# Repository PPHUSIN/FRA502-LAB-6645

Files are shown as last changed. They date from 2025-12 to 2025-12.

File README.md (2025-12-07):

# THRUST VECTORING DRONE
**FIBO FRA502 – RoboticsDev Final Project 2025**

**Institute of Field Robotics, King Mongkut's University of Technology Thonburi**

06 DEC, 2025

---

## 📋 สารบัญ

1. [Overview](#-overview)
2. [Project Objectives](#-project-objectives)
3. [Project Scope & Constraints](#-project-scope--constraints)
4. [System Architecture](#-system-architecture)
5. [General Information](#-general-information)
6. [Control System](#-control-system)
7. [Hardware Design](#-hardware-design)
8. [ROS2 Implementation](#-ros2-implementation)
   - [Simulation Mode](#simulation-mode-gazebo)
   - [Real Hardware Mode](#real-hardware-mode-esp32--microros)
9. [Expected Results](#-expected-results)
10. [Project Timeline](#-project-timeline)
11. [Installation & Setup](#-installation--setup)
12. [Usage](#-usage)

---

## 🎯 Overview

โครงงานนี้มีวัตถุประสงค์เพื่อพัฒนา **Thrust Vectoring Drone** (โดรนแบบควบคุมทิศทางแรงขับ) ซึ่งสามารถควบคุมทิศทางของแรงขับเพื่อการทรงตัวและเคลื่อนที่ได้อย่างอิสระ โดยใช้ระบบ **ROS2** ร่วมกับ **MicroROS** เพื่อเชื่อมต่อการสื่อสารระหว่างคอมพิวเตอร์และไมโครคอนโทรลเลอร์ในแบบเรียลไทม์

ระบบถูกออกแบบให้ฝั่งคอมพิวเตอร์ทำหน้าที่ส่งคำสั่งควบคุม (การขึ้นบิน, การเปลี่ยนทิศทาง, หรือการหยุดการทำงาน) ผ่าน Topic ส่วนฝั่งไมโครคอนโทรลเลอร์จะทำหน้าที่ประมวลผลทั้งหมด ได้แก่ การอ่านค่าจากเซนเซอร์ IMU, การคำนวณท่าทาง, และการควบคุมทิศทางของแรงขับด้วย LQR Controller

**คำสำคัญ:** ROS2, MicroROS, Monorotor Drone, LQR Controller, Real-Time Communication

---

## 🎯 Project Objectives

1. **เพื่อพัฒนาโดรนใบพัดเดียวที่ควบคุมด้วย Thrust Vectoring ได้อย่างเสถียร**
   - ใช้การปรับมุมเอียงของมอเตอร์เพื่อควบคุมทิศทางแรงขับแทนการเพิ่มจำนวนใบพัด
   - ช่วยลดน้ำหนักและความซับซ้อนของโครงสร้างโดรน

2. **เพื่อเชื่อมต่อระบบ ROS2 และ MicroROS สำหรับการสื่อสารและสั่งงานแบบเรียลไทม์ผ่าน Wi-Fi**
   - การสื่อสารผ่านอินเทอร์เน็ตโดยใช้ MicroROS Agent
   - ระบบทำงานแบบเรียลไทม์

3. **เพื่อศึกษาความสามารถในการทรงตัว การตอบสนองต่อคำสั่ง และความเป็นไปได้ในการต่อยอดสู่การควบคุมแบบอัตโนมัติในอนาคต**

---

## 📋 Project Scope & Constraints

### ขอบเขตโครงการ

1. ใช้ **ROS2** สำหรับส่งคำสั่งควบคุมการบิน
2. ใช้ไมโครคอนโทรลเลอร์ **ESP32** ที่รัน **MicroROS** ในการควบคุม LQR และการรักษาสมดุล
3. ระบบสื่อสารผ่าน **Wi-Fi Network / Local Network** โดยไม่ใช้ UART
4. ใช้ **IMU** ในการวัด pitch, roll, yaw ของโดรน
5. ใช้มอเตอร์ที่ปรับมุมเอียงได้ เพื่อสร้างการควบคุมแบบ **Thrust Vectoring**
6. แสดงผลและตรวจสอบสถานะโดรนผ่าน **Rviz**

### ข้อจำกัดการใช้งาน

- **ความสูงการบิน:** ไม่เกิน 4 เมตร
- **ระยะเวลาการบิน:** ไม่เกิน 5 นาที
- **พื้นที่ทดสอบ:** ในห้องปฏิบัติการหรือพื้นที่ปลอดภัย

---

## 🏗️ System Architecture

### System Overview

โปรเจกต์นี้มีขั้นตอนการทดสอบ 2 โหมด:

| Mode | Description | Data Source | Use Case |
|---|---|---|---|
| **🖥️ Simulation** | ทดสอบใน Gazebo | Gazebo Physics Engine | Development & Testing |
| **🚁 Real Hardware** | บินจริงด้วย ESP32 | ESP32 + MicroROS + Sensors | Real Flight |

### System Overview
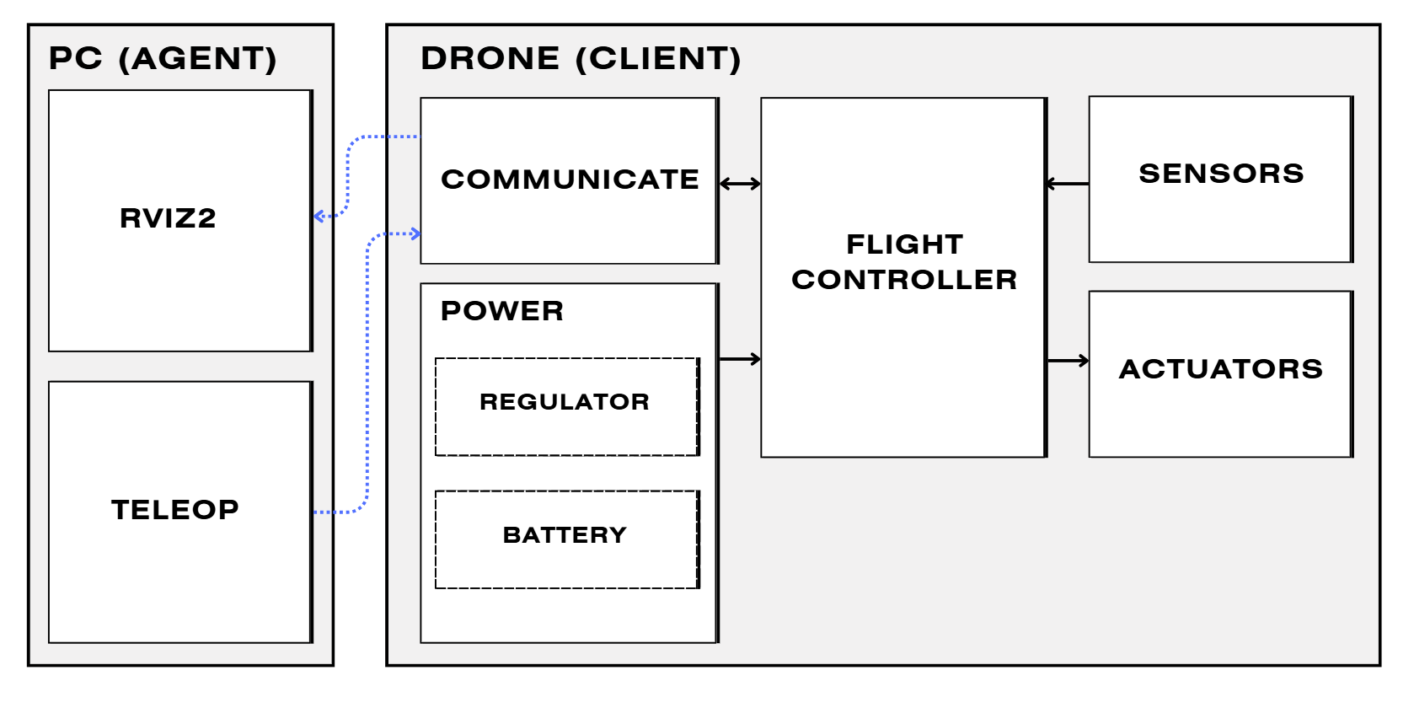
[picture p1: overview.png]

### System Architecture
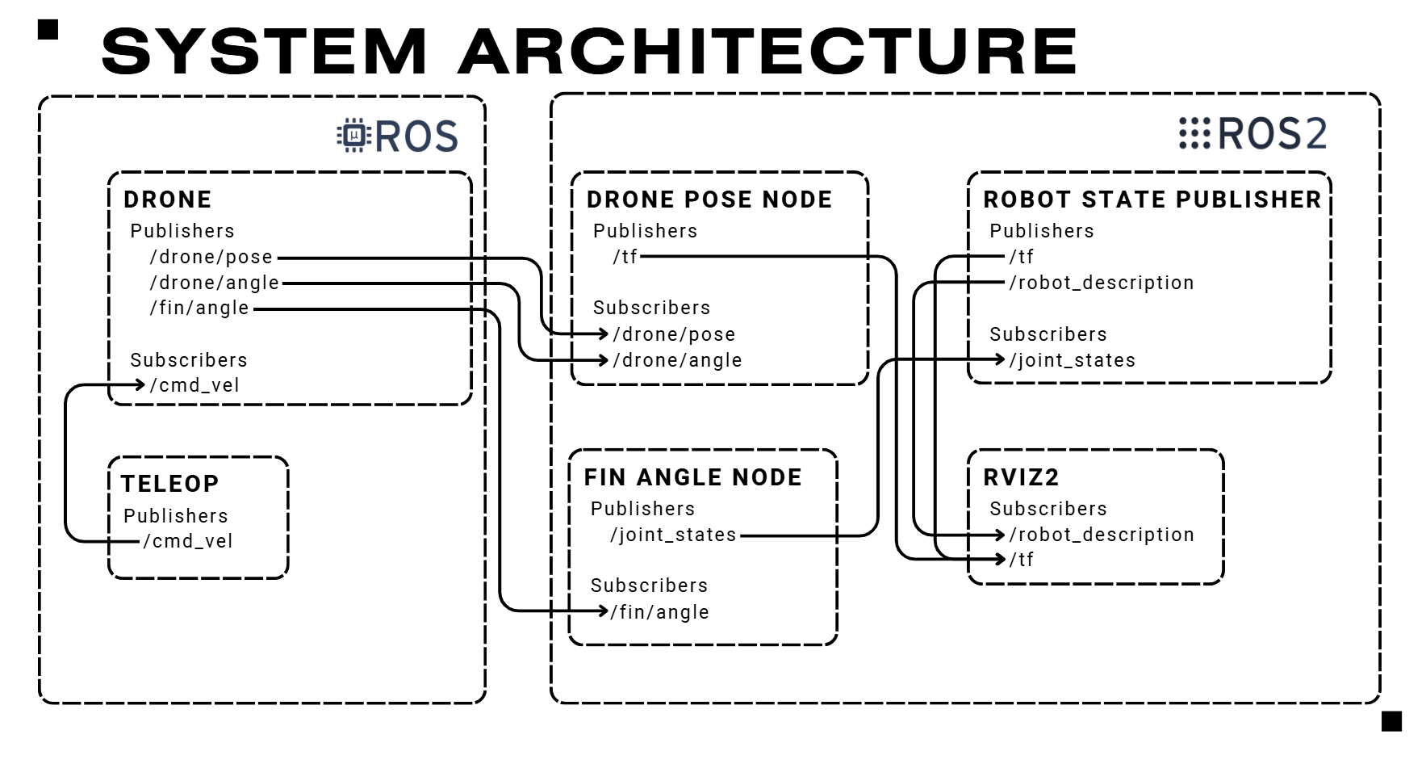
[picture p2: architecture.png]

### System Diagram
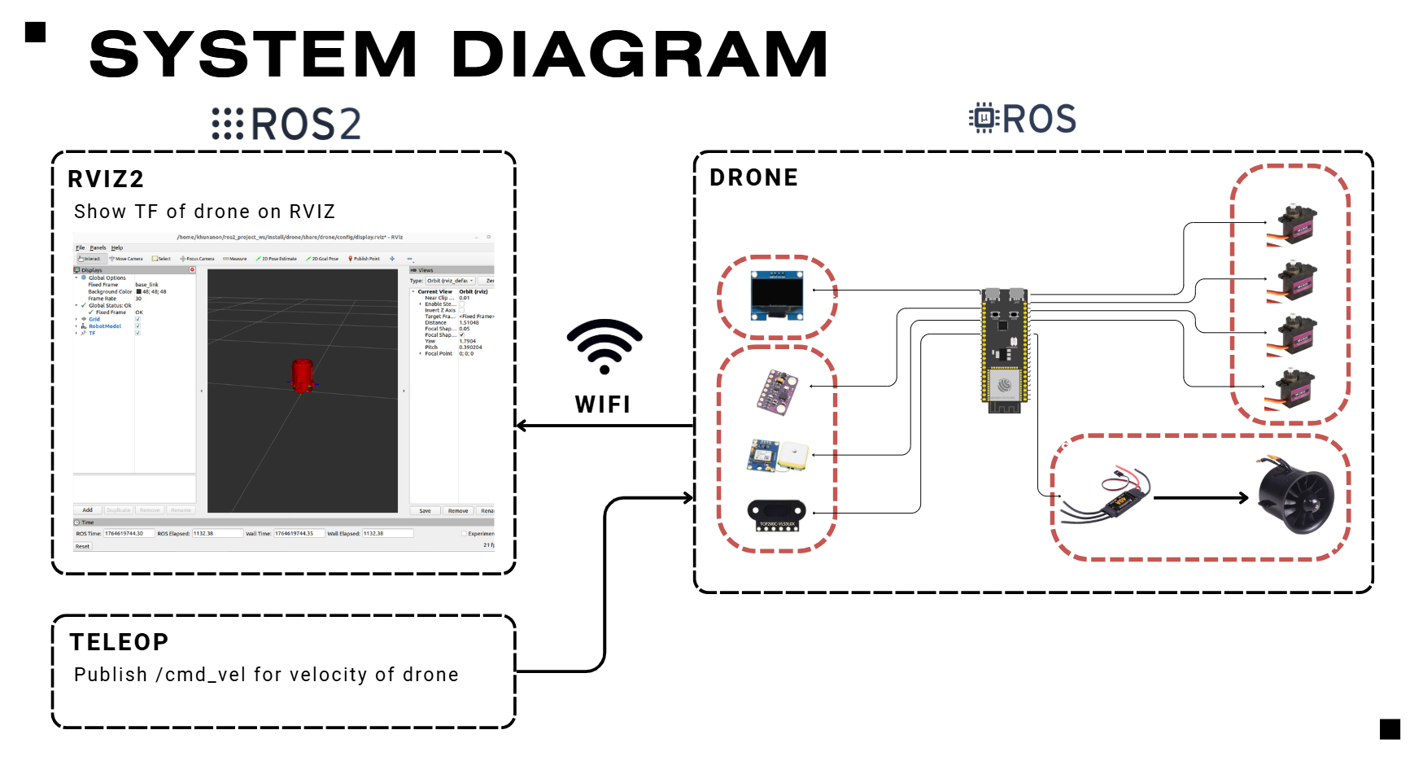
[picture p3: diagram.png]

---

## 📊 General Information

### Project Specifications

| Parameter | Value | Unit | Notes |
|---|---|---|---|
| **Platform** | ESP32 + MicroROS | - | Embedded flight controller |
| **Communication** | Wi-Fi/UDP | - | Real-time MicroROS Agent |
| **Flight Altitude** | ≤ 4 | meters | Safety constraint |
| **Flight Duration** | ≤ 5 | minutes | Battery limitation |
| **Control Type** | Thrust Vectoring | - | Single propeller + 4 fins |
| **Sensors** | IMU + TOF | - | Attitude + altitude sensing |

### Performance Targets

| Parameter | Target Accuracy | Unit | Description |
|---|---|---|---|
| **Attitude Control** | ±10 | degrees | Roll, Pitch, Yaw precision |
| **Altitude Control** | ±5 | cm | Height maintenance accuracy |
| **Communication** | Low latency | ms | ROS2 ↔ MicroROS stability |
| **Disturbance Rejection** | Small | - | LQR stability under wind |

---

# 🎮 ระบบควบคุม (Control System)

## 1. การสร้างแบบจำลองทางคณิตศาสตร์

โมโนคอปเตอร์ถูกจำลองเป็นวัตถุแข็งเกร่งที่มี **6 องศาอิสระ (6-DOF)** โดยพลวัตแบบไม่เชิงเส้นถูกอนุมานโดยใช้สมการนิวตัน-ออยเลอร์

### 1.1 ตัวแปรสถานะและอินพุต

**เวกเตอร์สถานะ (12 ตัวแปร):**
```
x = [φ  θ  ψ  ωx  ωy  ωz  x  y  z  vx  vy  vz]ᵀ
```

โดยที่:
- **φ, θ, ψ**: มุมโรล พิตช์ ยอว์ [rad]
- **ωx, ωy, ωz**: ความเร็วเชิงมุมในกรอบตัวโดรน [rad/s]
- **x, y, z**: ตำแหน่งในกรอบโลก [m]
- **vx, vy, vz**: ความเร็วเชิงเส้นในกรอบโลก [m/s]

**เวกเตอร์อินพุต (5 อินพุต):**
```
u = [α₁  α₂  α₃  α₄  ωt]ᵀ
```

โดยที่:
- **α₁₋₄**: มุมเอียงของครีบทั้ง 4 [rad]
- **ωt**: ความเร็วรอบของมอเตอร์ [rad/s]

### 1.2 พลวัตแบบไม่เชิงเส้น

#### พลวัตการหมุน (กรอบตัวโดรน)

การเร่งเชิงมุม **ω̇** ถูกกำหนดโดยโมเมนต์ที่เกิดจากครีบ (F₁...F₄) และโมเมนต์ความเฉื่อย **J**:

$$\begin{bmatrix} \dot{\omega}_x \\ \dot{\omega}_y \\ \dot{\omega}_z \end{bmatrix} = \begin{bmatrix} \frac{l}{J_{xx}}(F_1 + F_3) \\ \frac{l}{J_{yy}}(F_2 + F_4) \\ \frac{r}{J_{zz}}(F_1 - F_2 - F_3 + F_4) \end{bmatrix} + \begin{bmatrix} \frac{1}{J_{xx}}(J_{yy} - J_{zz})\omega_y \omega_z \\ \frac{1}{J_{yy}}(J_{zz} - J_{xx})\omega_x \omega_z \\ \frac{1}{J_{zz}}(J_{xx} - J_{yy})\omega_x \omega_y \end{bmatrix}$$

**พารามิเตอร์:**
- **l**: ระยะห่างจากจุดศูนย์กลางมวลไปยังข้อต่อครีบ [m]
- **r**: ระยะห่างจากแกน z ไปยังจุดกึ่งกลางครีบ [m] 
- **Fn**: แรงที่เกิดจากครีบที่ n ซึ่งเป็นฟังก์ชันของมุมครีบ αn และแรงขับมอเตอร์ Ft

#### พลวัตการเคลื่อนที่ (กรอบเฉื่อย)

การเร่งเชิงเส้นได้จากการหมุนแรงในกรอบตัวโดรนไปยังกรอบโลกโดยใช้เมทริกซ์หมุน **R^w_b**:

$$\begin{bmatrix} \dot{v}_x \\ \dot{v}_y \\ \dot{v}_z \end{bmatrix} = R_b^w \frac{1}{m} \begin{bmatrix} F_2 + F_4 \\ F_1 + F_3 \\ F_t - F_d \end{bmatrix} - \begin{bmatrix} 0 \\ 0 \\ g \end{bmatrix}$$

โดยที่:
- **Ft**: แรงขับรวมของมอเตอร์ [N]
- **Fd**: แรงต้านจากครีบ [N]
- **g**: ความเร่งจากแรงโน้มถ่วง [m/s²]

#### จลนศาสตร์ท่าทาง

ความสัมพันธ์ระหว่างความเร็วเชิงมุมในกรอบตัวโดรนกับอัตราการเปลี่ยนแปลงมุมออยเลอร์:

$$\begin{bmatrix} \dot{\phi} \\ \dot{\theta} \\ \dot{\psi} \end{bmatrix} = \begin{bmatrix} 1 & \sin\phi\tan\theta & \cos\phi\tan\theta \\ 0 & \cos\phi & -\sin\phi \\ 0 & \sin\phi/\cos\theta & \cos\phi/\cos\theta \end{bmatrix} \begin{bmatrix} \omega_x \\ \omega_y \\ \omega_z \end{bmatrix}$$

### 1.3 การทำให้เป็นเชิงเส้น

เพื่อออกแบบตัวควบคุม LQR ระบบจะถูกเชิงเส้นรอบ**จุดสมดุลการลอยตัว** โดยที่:
- φ = 0, θ = 0, ψ = 0 (ท่าทางราบ)
- ความเร็วทั้งหมด = 0 (ลอยนิ่ง)
- แรงขับรวมเท่ากับแรงโน้มถ่วง: **Ft = mg**

**แบบจำลอง state-space เชิงเส้น** ที่ได้คือ ẋ = Ax + Bu:

$$A = \begin{bmatrix} 0_{3 \times 3} & I_3 & 0_{3 \times 3} & 0_{3 \times 3} \\ 0_{3 \times 3} & 0_{3 \times 3} & 0_{3 \times 3} & 0_{3 \times 3} \\ 0_{3 \times 3} & 0_{3 \times 3} & 0_{3 \times 3} & I_3 \\ 0_{3 \times 3} & G & 0_{3 \times 3} & 0_{3 \times 3} \end{bmatrix}, \quad B = \begin{bmatrix} 0_{3 \times 5} \\ B_{rot} \\ 0_{3 \times 5} \\ B_{trans} \end{bmatrix}$$

โดยที่:
- **G**: เมทริกซ์คู่ควบแรงโน้มถ่วงที่มีพจน์ g
- **B_rot**: เมทริกซ์ประสิทธิผลการควบคุมการหมุนที่ประกอบด้วยสัมประสิทธิ์เชิงเส้น C_L·C_F/J
- **B_trans**: เมทริกซ์ประสิทธิผลการควบคุมการเคลื่อนที่ที่ประกอบด้วยสัมประสิทธิ์ C_L·C_F/m

## 2. กลยุทธ์การแยกสถานะ

เพื่อทำให้การออกแบบและการใช้งานตัวควบคุมง่ายขึ้น ระบบ 12 ตัวแปรจะถูกแยกเป็น **2 ระบบย่อย** ที่มีช่วงเวลาตอบสนองต่างกัน:

### 2.1 พลวัตเร็ว (ระบบย่อยการลอยตัว)
```
x_hov = [φ  θ  ψ  ωx  ωy  ωz  z  vz]ᵀ  (8 ตัวแปร)
```
- **สถานะท่าทาง**: Roll, pitch, yaw และอัตราการเปลี่ยนแปลง
- **สถานะความสูง**: ตำแหน่งและความเร็วแนวดิ่ง
- **ลักษณะเฉพาะ**: พลวัตเร็ว สามารถควบคุมได้โดยตรง
- **อัตราอัพเดต**: 100 Hz

### 2.2 พลวัตช้า (ระบบย่อยตำแหน่ง)  
```
x_pos = [x  y  vx  vy]ᵀ  (4 ตัวแปร)
```
- **ตำแหน่งแนวนอน**: พิกัด x, y  
- **ความเร็วแนวนอน**: องค์ประกอบ vx, vy
- **ลักษณะเฉพาะ**: พลวัตช้ากว่า ควบคุมทางอ้อมผ่านท่าทาง
- **อัตราอัพเดต**: -

### 2.3 สถาปัตยกรรมการควบคุม

```
ตัวควบคุมตำแหน่ง → ตัวควบคุมลอยตัว → พลวัตของโดรน
  (Outer Loop)       (Inner Loop)      (Monocopter)
       ↑                  ↑                 ↓
       └──────────────────┴──── Estimator ←─ เซนเซอร์
```

**ประโยชน์ของการแยกสถานะ:**
1. **การแยกช่วงเวลาตามธรรมชาติ**: ควบคุมท่าทางเร็ว ควบคุมตำแหน่งช้ากว่า
2. **การออกแบบแบบโมดูล**: สามารถออกแบบและปรับแต่งตัวควบคุมแยกกันได้  
3. **การใช้งานจริง**: สอดคล้องกับอัตราอัพเดตของเซนเซอร์และข้อจำกัดการคำนวณ
4. **โครงสร้างแบบลำดับชั้น**: ตัวควบคุมตำแหน่งสั่งค่าอ้างอิงท่าทาง

## 3. การออกแบบตัวควบคุม LQR

### 3.1 ตัวควบคุมการลอยตัว (วงในของ Cascade)

**วัตถุประสงค์**: รักษาเสถียรภาพท่าทาง (φ, θ, ψ) และความสูง (z) โดยใช้การควบคุมครีบโดยตรง

#### การเสริมสถานะด้วยการกระทำแบบอินทิกรัล

เพื่อขจัดข้อผิดพลาดในสภาวะคงที่ (เช่น จากแรงดันแบตเตอรี่ลดลง จุดศูนย์กลางมวลเยื้อง) ตัวควบคุมการลอยตัวจะเสริมด้วยสถานะอินทิกรัลสำหรับความสูง:

```
x_hov_aug = [φ  θ  ψ  ωx  ωy  ωz  z  vz  ∫ez]ᵀ  (9 ตัวแปร)
```

โดยที่ **∫ez** คือค่าอินทิกรัลของข้อผิดพลาดความสูง

#### เอาต์พุตการควบคุม
```
u_hov = [α₁  α₂  α₃  α₄  ωt]ᵀ  
```

#### การปรับแต่ง LQR (กฎของบรายสัน)

**ค่าปรับแบบการกระทำ (เมทริกซ์ R):**
- มุมเอียงครีบสูงสุด: ±10°
- การเปลี่ยนแปลงความเร็วมอเตอร์สูงสุด: ±1000 RPM

$$R_{hov} = \text{diag}\left( \frac{1}{(10°)^2}, \frac{1}{(10°)^2}, \frac{1}{(10°)^2}, \frac{1}{(10°)^2}, \frac{1}{(1000)^2} \right)$$

**ค่าปรับสถานะ (เมทริกซ์ Q):**
- **ท่าทาง (ควบคุมเข้มงวด)**: ข้อผิดพลาดสูงสุด 0.1 rad (≈ 6°) สำหรับ roll/pitch
- **Yaw (ผ่อนปรน)**: ข้อผิดพลาดสูงสุด 1.0 rad เพื่อป้องกันครีบอิ่มตัว  
- **ความสูง**: ข้อผิดพลาดสูงสุด 0.25 m
- **อัตราเชิงมุม**: สูงสุด 1-2 rad/s
- **ความเร็วแนวดิ่ง**: สูงสุด 1 m/s

$$Q_{hov} = \text{diag}\left( \frac{1}{0.1^2}, \frac{1}{0.1^2}, \frac{1}{1.0^2}, \frac{1}{1^2}, \frac{1}{1^2}, \frac{1}{2^2}, \frac{1}{0.25^2}, \frac{1}{1^2}, \frac{1}{0.15^2} \right)$$

#### การป้องกัน Anti-Windup

เพื่อป้องกัน integrator windup โดยเฉพาะอย่างยิ่งในช่วงขึ้นบิน:
```
if |∫ez| > windup_limit:
    ∫ez = sign(∫ez) × windup_limit
```

### 3.2 ตัวควบคุมตำแหน่ง (วงนอกของ Cascade)

**วัตถุประสงค์**: ติดตามตำแหน่งแนวนอน (x, y) โดยสร้างค่าอ้างอิง roll/pitch สำหรับตัวควบคุมการลอยตัว

#### การเสริมสถานะด้วยการกระทำแบบอินทิกรัล

เพื่อแก้ไขความไม่ตรงของกลไกและข้อผิดพลาดท่าทางในสภาวะคงที่:

```
x_pos_aug = [x  y  vx  vy  ∫ex  ∫ey]ᵀ  (6 ตัวแปร)
```

โดยที่ **∫ex, ∫ey** คือค่าอินทิกรัลของข้อผิดพลาดตำแหน่ง

#### เอาต์พุตการควบคุม
```
u_pos = [φref  θref]ᵀ  (ค่าอ้างอิงท่าทาง)
```

#### การปรับแต่ง LQR

**ค่าปรับแบบการกระทำ (เมทริกซ์ R):**
- ค่าอ้างอิงท่าทางสูงสุด: ±0.1 rad (≈ ±6°)

$$R_{pos} = \text{diag}\left( \frac{1}{0.1^2}, \frac{1}{0.1^2} \right)$$

**ค่าปรับสถานะ (เมทริกซ์ Q):**
- **ตำแหน่ง**: ข้อผิดพลาดสูงสุด 0.5 m
- **ความเร็ว**: สูงสุด 1 m/s  
- **พจน์อินทิกรัล**: ปรับแต่งเพื่อขจัดสภาวะคงที่

$$Q_{pos} = \text{diag}\left( \frac{1}{0.5^2}, \frac{1}{0.5^2}, \frac{1}{1^2}, \frac{1}{1^2}, \frac{1}{1^2}, \frac{1}{1^2} \right)$$

---

## 🔧 Hardware Design

### Thrust Vane Mechanism
GIF demo
```
┌──────────────────────────────────────┐
│      THRUST VANE FORCE               │
│                                      │
│           ┌────────┐                 │
│           │ SERVO  │                 │
│           │ MOTOR  │                 │
│           └───┬────┘                 │
│               │                      │
│         ┌─────▼─────┐                │
│         │   THRUST  │                │
│         │    VANE   │                │
│         └───────────┘                │
│               │                      │
│               ▼                      │
│         Vectored Thrust              │
└──────────────────────────────────────┘
```

## Airfoil Design

Thrust Vane คือ "ครีบบังคับทิศทาง" ที่ติดอยู่บริเวณส่วนล่างของหุ่น

---

รูปร่างของ Thrust Vane ส่งผลโดยตรงต่อ:
- **แรงยก (Lift)** - แรงที่ใช้ควบคุมทิศทาง
- **แรงต้าน (Drag)** - พลังงานที่สูญเสียไป

---

### Thrust Vane Requiment

1. **ควบคุมได้ทั้งสองทิศทาง** - เอียงซ้ายหรือเอียงขวาได้ เท่าๆ กัน
2. **ตอบสนองเป็นเส้นตรง** - ยิ่งเอียงมากยิ่งได้แรงมาก
3. **แรงต้านต่ำ** - ไม่เปลืองพลังงาน

---

### รูปร่างของ Thrust Vane

เราได้เลือก Thrust Vane ที่เป็นรูปร่างแบบ Joukowski 9%

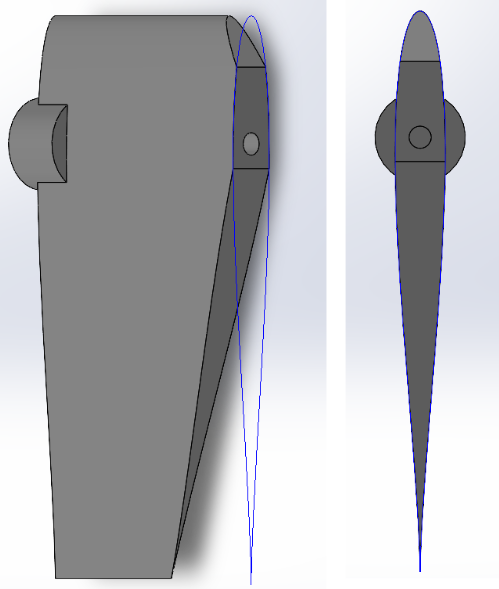
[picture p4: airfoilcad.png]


Joukowski 9% หมายถึง
- **f=0%** คือ ความโค้งของเส้นเป็น 0 (สมมาตร)
- **t=9%** คือ ความหนาสูงสุดของ airfoil 

เนื่องจากในรายงานบอกว่าเพื่อลดเวลาในการหาค่า coefficient สำหรับ thrust vane แบบ custom จึงเลือกใช้ airfoil ที่มีอยู่แล้ว

### ค่าที่ได้จาก Joukowski 9%

จากข้อมูลที่จำลองด้วย XFoil:

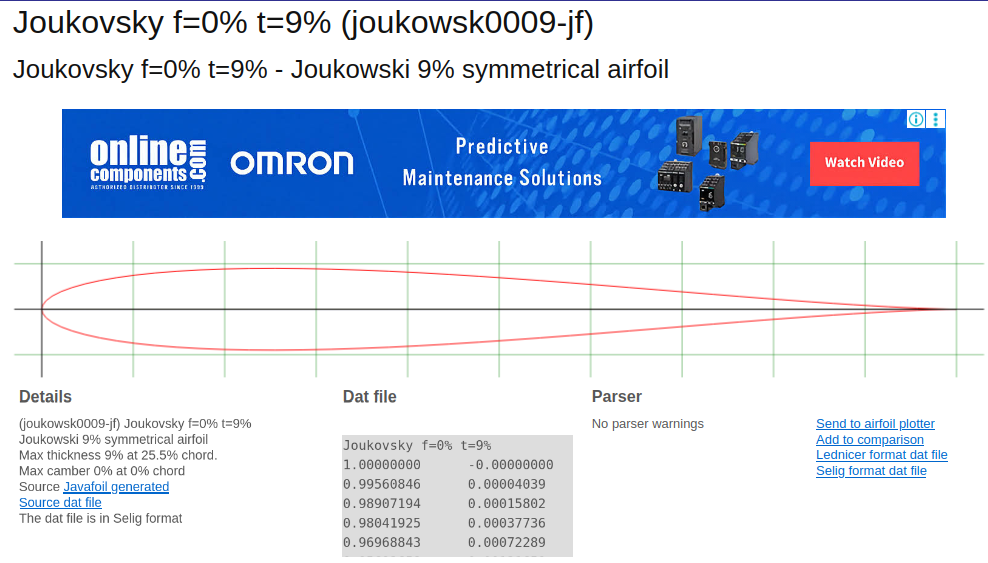
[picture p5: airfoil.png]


| ค่า | ความหมาย | ประโยชน์ |
|-----|---|---|
| **CLα = 0.1081** | เอียง 1° ได้แรงยก 0.1081 หน่วย | ทำนายแรงได้ง่าย |
| **CD0 = 0.0145** | แรงต้านคงที่ตลอด | ไม่ต้องชดเชย |

ค่าทั้งสองเป็น "ค่าคงที่" ในช่วงมุม ±10° ทำให้ใช้กับ Linear Controller (LQR) 

---

### นำไปใช้กับ LQR

ค่าที่ได้ถูกใส่ในสมการควบคุม:

```
แรงที่ได้ = Ft × CL × มุมที่เอียง

โดย:
  Ft = แรงขับจากมอเตอร์
  CL = ค่าคงที่จาก Joukowski (0.1081)
```

ระบบควบคุม LQR ใช้สมการนี้ในการคำนวณ:
- **Roll** (เอียงซ้าย-ขวา)
- **Pitch** (เอียงหน้า-หลัง)  
- **Yaw** (หมุนรอบตัว)
---

## 🚀 ROS2 Implementation

ตอนนี้โปรเจกต์แยกเป็น 2 ส่วนการทำงานที่ใช้ **Python files**, topics และ data flow ที่แตกต่างกัน:

---

### 🖥️ Simulation Mode (Gazebo)

> **สถานะ:** ✅ ใช้งานอยู่ในปัจจุบันสำหรับการพัฒนาและทดสอบ(***โดยใช้ Gazebo classic อ่านเพิ่มเติมที่ Readme.md ใน Gazebo***)

ในโหมด Simulation ข้อมูลทั้งหมดมาจาก **Gazebo Physics Engine** โดย RVIZ จะแสดงผลข้อมูลที่ได้จาก simulation

#### Python Files สำหรับ Simulation

| File | Node Name | Description |
|---|---|---|
| `drone_pose_sim.py` | `drone_pose_node` | อ่านข้อมูล Odometry จาก Gazebo (`/odom`) แปลง quaternion เป็น euler แล้ว broadcast TF |
| `fin_sim.py` | `fin_pose_node` | อ่าน TF ของ fins จาก Gazebo แล้ว broadcast TF สำหรับแต่ละ fin |
| `teleop_sim.py` | `teleop_sim_node` | รับ keyboard input แล้ว publish velocity setpoint ให้โดรน (`/drone/velocity_setpoint`) |

#### Simulation System Architecture

```
┌─────────────────────────────────────────────────────────────────────┐
│                        GAZEBO SIMULATION                            │
│                                                                     │
│  • Physics Engine          • Drone Model        • Environment       │
│                                                                     │
│  Publishers:                      Subscribers:                      │
│  • /odom (position & velocity)    • /drone/velocity_setpoint        │
│  • /tf (world transforms)                                           │
└───────────────────────────────┬─────────────────────────────────────┘
                                │
                                │ ROS2 Topics
                                ▼
┌─────────────────────────────────────────────────────────────────────┐
│                         PC (ROS2 NODES)                             │
│                                                                     │
│  ┌─────────────────┐  ┌─────────────────┐  ┌─────────────────┐     │
│  │  TELEOP_SIM     │  │ DRONE_POSE_SIM  │  │    FIN_SIM      │     │
│  │  (teleop_sim.py)│  │(drone_pose_sim) │  │  (fin_sim.py)   │     │
│  │                 │  │                 │  │                 │     │
│  │ Pub:            │  │ Sub: /odom      │  │ Sub: /tf        │     │
│  │ /drone/         │  │    (Gazebo)     │  │    (Gazebo)     │     │
│  │ velocity_       │  │                 │  │                 │     │
│  │ setpoint        │  │ Pub: /tf        │  │ Pub: /tf        │     │
│  │     │           │  │ (base_link      │  │ (fin_X_link)    │     │
│  │     │           │  │  →body_drone)   │  │                 │     │
│  └─────┼───────────┘  └──────┬──────────┘  └──────┬──────────┘     │
│        │                     │                    │                 │
│        │ To Gazebo           ▼                    ▼                 │
│  ┌─────────────────────────────────────────────────────────────┐   │
│  │                        RVIZ2                                │   │
│  │  • Drone 3D Model      ← /robot_description                 │   │
│  │  • Position/Orientation ← /tf (from Gazebo)                 │   │
│  │  • Fin Poses           ← /tf (from fin_sim)                 │   │
│  └─────────────────────────────────────────────────────────────┘   │
└─────────────────────────────────────────────────────────────────────┘
```

#### Simulation Nodes Detail

##### 1. Drone Pose Sim Node (drone_pose_sim.py)

```python
# Node: drone_pose_node

# Subscribers
/odom                # Odometry data from Gazebo (nav_msgs/Odometry)
                     # Contains: position (x,y,z) + orientation (quaternion)

# Publishers
/tf                  # Transform: base_link → body_drone
                     # Converts quaternion to euler angles (roll, pitch, yaw)
```

**หน้าที่หลัก:**
- รับข้อมูล position และ orientation จาก Gazebo ผ่าน `/odom`
- แปลง quaternion เป็น euler angles
- Broadcast TF transform จาก `base_link` ไป `body_drone`

##### 2. Fin Sim Node (fin_sim.py)

```python
# Node: fin_pose_node

# Subscribers
/tf                  # TF transforms from Gazebo (tf2_msgs/TFMessage)
                     # Listens for: fin_1, fin_2, fin_3, fin_4

# Publishers
/tf                  # Transform: body_drone → fin_X_link
                     # Publishes individual fin transforms
```

**หน้าที่หลัก:**
- รับ TF ของแต่ละ fin จาก Gazebo
- คำนวณมุมจาก translation (x, y)
- Broadcast TF สำหรับแต่ละ fin

##### 3. Teleop Sim Node (teleop_sim.py)

```python
# Node: teleop_sim_node

# Publishers
/drone/velocity_setpoint    # Velocity setpoint for drone (geometry_msgs/Vector3)

# Controls (World Frame):
#   w : +X (Forward)    speed = 1.0 m/s
#   s : -X (Backward)
#   a : +Y (Left)
#   d : -Y (Right)
#   space : +Z (Up)
#   c : -Z (Down)
#   CTRL-C : Quit
```

**หน้าที่หลัก:**
- รับ keyboard input จาก user
- Publish velocity setpoint เป็น `Vector3` message
- โดรนจะใช้ setpoint นี้เป็นเป้าหมายความเร็วในการควบคุม

#### Simulation Topic Summary

| Topic | Message Type | Publisher | Subscriber |
|---|---|---|---|
| `/odom` | nav_msgs/Odometry | **Gazebo** | drone_pose_sim |
| `/tf` | tf2_msgs/TFMessage | drone_pose_sim, fin_sim, **Gazebo** | RVIZ2 |
| `/drone/velocity_setpoint` | geometry_msgs/Vector3 | teleop_sim | **Drone** (setpoint) |
| `/robot_description` | std_msgs/String | robot_state_publisher | RVIZ2 |

### 🚁 Real Hardware Mode (ESP32 + MicroROS)

> **สถานะ:** ⏳ อยู่ระหว่างการพัฒนา - **ไฟล์ถูกสร้างไว้แล้วแต่ยังไม่ได้ทดสอบกับฮาร์ดแวร์จริง**

ในโหมด Real Hardware ข้อมูลมาจาก **ESP32 + MicroROS** ที่อ่านค่าจาก sensors จริง (IMU, TOF) และส่งผ่าน Wi-Fi

#### Python Files สำหรับ Real Hardware

| File | Node Name | Status | Description |
|---|---|---|---|
| `drone_pose.py` | `drone_pose_node` | ⚠️ **รอทดสอบ** | รับข้อมูล angle จาก ESP32 (`/drone/angle`) และ velocity (`/cmd_vel`) แล้ว broadcast TF |
| `fin_angle.py` | `fin_angle_node` | ⚠️ **รอทดสอบ** | รับมุม fin จาก ESP32 (`/fin_angle`) แล้ว publish JointState (`/fin_states`) |
| `teleop.py` | `teleop_node` | ⚠️ **รอทดสอบ** | รับ keyboard input แล้ว publish velocity setpoint ให้โดรน (`/cmd_vel`) |

> ⚠️ **หมายเหตุ:** ไฟล์เหล่านี้ถูกสร้างไว้เพื่อเตรียมใช้งานกับ Real Hardware แต่ยังไม่ได้ทดสอบกับ ESP32 และ MicroROS จริง รอการพัฒนาใน Week 3-4

#### Real Hardware System Architecture

```
┌─────────────────────────────────────────────────────────────────────┐
│                    ESP32 + MicroROS (DRONE)                         │
│                                                                     │
│  ┌──────────────────────────────────────────────────────────────┐  │
│  │                    FLIGHT CONTROLLER                         │  │
│  │                                                              │  │
│  │  ┌─────────────┐  ┌─────────────┐  ┌─────────────┐         │  │
│  │  │     IMU     │  │ TOF SENSOR  │  │ LQR CONTROL │         │  │
│  │  │  (MPU6050)  │  │             │  │             │         │  │
│  │  │             │  │ • Altitude  │  │ • Roll      │         │  │
│  │  │ • Roll      │  │             │  │ • Pitch     │         │  │
│  │  │ • Pitch     │  └──────┬──────┘  │ • Yaw       │         │  │
│  │  │ • Yaw       │         │         │ • Altitude  │         │  │
│  │  └──────┬──────┘         │         └──────┬──────┘         │  │
│  │         │                │                │                 │  │
│  │         └────────────────┴────────────────┘                 │  │
│  │                          │                                   │  │
│  │                          ▼                                   │  │
│  │  ┌───────────────────────────────────────────────────────┐  │  │
│  │  │              MicroROS NODE                            │  │  │
│  │  │                                                       │  │  │
│  │  │  Publishers:                                         │  │  │
│  │  │  • /drone/pose        (geometry_msgs/Pose)          │  │  │
│  │  │  • /drone/imu         (sensor_msgs/Imu)             │  │  │
│  │  │  • /drone/status      (diagnostic_msgs/Status)      │  │  │
│  │  │  • /drone/angle       (std_msgs/Float64MultiArray)  │  │  │
│  │  │  • /fin_angle         (std_msgs/Float64MultiArray)  │  │  │
│  │  │                                                       │  │  │
│  │  │  Subscribers:                                        │  │  │
│  │  │  • /cmd_vel           (geometry_msgs/Twist)         │  │  │
│  │  │  • /drone/setpoint    (geometry_msgs/Point)         │  │  │
│  │  └───────────────────────────────────────────────────────┘  │  │
│  └──────────────────────────────────────────────────────────────┘  │
│                                                                     │
│  ┌──────────────────────────────────────────────────────────────┐  │
│  │                    HARDWARE INTERFACE                        │  │
│  │                                                              │  │
│  │  • 4x Servo Motors (Fin Control)                            │  │
│  │  • 1x ESC + Brushless Motor (Thrust)                        │  │
│  └──────────────────────────────────────────────────────────────┘  │
└───────────────────────────────┬─────────────────────────────────────┘
                                │
                           UDP  │ Wi-Fi (MicroROS Agent)
                                ▼
┌─────────────────────────────────────────────────────────────────────┐
│                         PC (ROS2 NODES)                             │
│                                                                     │
│  ┌─────────────────┐  ┌─────────────────┐  ┌─────────────────┐     │
│  │  MicroROS Agent │  │   DRONE_POSE    │  │    FIN_ANGLE    │     │
│  │                 │  │ (drone_pose.py) │  │ (fin_angle.py)  │     │
│  │ • UDP Bridge    │  │                 │  │                 │     │
│  │ • Topic Relay   │  │ Sub: /drone/    │  │ Sub: /fin_angle │     │
│  └────────┬────────┘  │      angle      │  │                 │     │
│           │           │      /cmd_vel   │  │ Pub: /fin_states│     │
│           │           │                 │  │                 │     │
│           │           │ Pub: /tf        │  └────────┬────────┘     │
│           │           └────────┬────────┘           │              │
│           │                    │                    │              │
│  ┌────────┴────────┐           ▼                    ▼              │
│  │     TELEOP      │  ┌────────────────────────────────────────┐   │
│  │  (teleop.py)    │  │                RVIZ2                   │   │
│  │                 │  │                                        │   │
│  │ Pub: /cmd_vel   │  │  Subscribers:                          │   │
│  └─────────────────┘  │  • /tf           ← Position from ESP32 │   │
│                       │  • /fin_states   ← Fin angles          │   │
│                       │  • /robot_description                  │   │
│                       └────────────────────────────────────────┘   │
└─────────────────────────────────────────────────────────────────────┘
```

#### Real Hardware Nodes Detail

##### 1. Drone Pose Node (drone_pose.py) ⚠️ รอทดสอบ

```python
# Node: drone_pose_node

# Subscribers
/drone/angle         # Float64MultiArray from ESP32 [roll, pitch, yaw]
/cmd_vel             # Twist from teleop (linear velocity commands)

# Publishers  
/tf                  # Transform: base_link → body_drone

# Timer
dt = 0.01s (100 Hz)  # Update rate for pose calculation
```

**หน้าที่หลัก:**
- รับ roll, pitch, yaw จาก ESP32 ผ่าน `/drone/angle`
- รับ velocity commands จาก `/cmd_vel`
- คำนวณ position จาก velocity integration
- Broadcast TF transform

**ความแตกต่างจาก Simulation:**
- ไม่ใช้ `/odom` จาก Gazebo
- รับข้อมูลโดยตรงจาก ESP32 sensors
- ใช้ velocity integration แทน direct position

##### 2. Fin Angle Node (fin_angle.py) ⚠️ รอทดสอบ

```python
# Node: fin_angle_node

# Subscribers
/fin_angle           # Float64MultiArray from ESP32 [fin1, fin2, fin3, fin4]

# Publishers
/fin_states          # JointState message
                     # Joints: fin_1_joint, fin_2_joint, fin_3_joint, fin_4_joint
```

**หน้าที่หลัก:**
- รับมุม fin จาก ESP32 ผ่าน `/fin_angle`
- Publish JointState สำหรับ robot_state_publisher
- แสดงผลใน RVIZ

**ความแตกต่างจาก Simulation:**
- รับข้อมูลจาก ESP32 แทน Gazebo TF
- ใช้ JointState message โดยตรง

##### 3. Teleop Node (teleop.py) ⚠️ รอทดสอบ

```python
# Node: teleop_node

# Publishers
/cmd_vel             # Velocity setpoint for drone (geometry_msgs/Twist)

# Controls (World Frame):
#   w : +X (Forward)    speed = 0.1 m/s
#   s : -X (Backward)
#   a : +Y (Left)
#   d : -Y (Right)
#   space : +Z (Up)
#   c : -Z (Down)
#   CTRL-C : Quit
```

**หน้าที่หลัก:**
- รับ keyboard input
- Publish velocity setpoint เป็น Twist message
- โดรนจะใช้ setpoint นี้เป็นเป้าหมายความเร็วในการควบคุม

**ความแตกต่างจาก Simulation:**
- ใช้ `Twist` message แทน `Vector3`
- Speed ต่ำกว่า (0.1 vs 1.0 m/s) สำหรับความปลอดภัย
- Publish ไป `/cmd_vel` แทน `/drone/velocity_setpoint`

#### Real Hardware Topic Summary

| Topic | Message Type | Publisher | Subscriber |
|---|---|---|---|
| `/drone/pose` | geometry_msgs/Pose | **ESP32** | RVIZ2 |
| `/drone/imu` | sensor_msgs/Imu | **ESP32** | RVIZ2 |
| `/drone/angle` | std_msgs/Float64MultiArray | **ESP32** | drone_pose |
| `/drone/status` | diagnostic_msgs/Status | **ESP32** | Monitor |
| `/fin_angle` | std_msgs/Float64MultiArray | **ESP32** | fin_angle |
| `/fin_states` | sensor_msgs/JointState | fin_angle | robot_state_publisher |
| `/cmd_vel` | geometry_msgs/Twist | teleop | **Drone** (setpoint), drone_pose |
| `/drone/setpoint` | geometry_msgs/Point | PC | **ESP32** |

### 📊 Mode Comparison

#### Python Files Comparison

| Function | 🖥️ Simulation | 🚁 Real Hardware | Status |
|---|---|---|---|
| **Drone Pose** | `drone_pose_sim.py` | `drone_pose.py` | Sim ✅ / Real ⚠️ |
| **Fin Control** | `fin_sim.py` | `fin_angle.py` | Sim ✅ / Real ⚠️ |
| **Teleop** | `teleop_sim.py` | `teleop.py` | Sim ✅ / Real ⚠️ |

#### Feature Comparison

| Feature | 🖥️ Simulation | 🚁 Real Hardware |
|---|---|---|
| **Data Source** | Gazebo Physics | ESP32 Sensors |
| **Position Topic** | `/odom` | `/drone/angle` + integration |
| **Fin Data Topic** | `/tf` (Gazebo) | `/fin_angle` (ESP32) |
| **Control Input** | `/drone/velocity_setpoint` | `/cmd_vel` |
| **Control Message** | `Vector3` (velocity setpoint) | `Twist` (velocity setpoint) |
| **Default Speed** | 1.0 m/s | 0.1 m/s |
| **Communication** | Local ROS2 | Wi-Fi + MicroROS |
| **RVIZ Config** | `rviz_launch.py` | `rviz_real_launch.py` |
| **Use Case** | Development, Testing | Flight Testing |

### Topic Mapping

```
┌─────────────────────────────────────────────────────────────────┐
│                    TOPIC COMPARISON                             │
├─────────────────────────┬───────────────────────────────────────┤
│   🖥️ SIMULATION         │   🚁 REAL HARDWARE                    │
├─────────────────────────┼───────────────────────────────────────┤
│ /odom                   │ /drone/angle                          │
│ (nav_msgs/Odometry)     │ (std_msgs/Float64MultiArray)          │
│ Source: Gazebo          │ Source: ESP32 + IMU                   │
├─────────────────────────┼───────────────────────────────────────┤
│ /tf (from Gazebo)       │ /fin_angle                            │
│ (fin transforms)        │ (std_msgs/Float64MultiArray)          │
│                         │ Source: ESP32 servo feedback          │
├─────────────────────────┼───────────────────────────────────────┤
│ /drone/velocity_setpoint│ /cmd_vel                              │
│ (geometry_msgs/Vector3) │ (geometry_msgs/Twist)                 │
│ To: Drone (setpoint)    │ To: Drone (setpoint)                  │
├─────────────────────────┼───────────────────────────────────────┤
│ N/A                     │ /fin_states                           │
│                         │ (sensor_msgs/JointState)              │
│                         │ To: robot_state_publisher             │
└─────────────────────────┴───────────────────────────────────────┘
```
# ESP32-S3 Software 

## ภาพรวม
นี่คือเฟิร์มแวร์ควบคุมการบินสำหรับโดรนแบบ thrust-vectoring ที่ใช้ ESP32-S3 ระบบผสานการทำงานของ IMU sensor fusion, GPS positioning, เซนเซอร์วัดระยะ time-of-flight และการสื่อสารผ่าน ROS2 เพื่อควบคุมการบินอัตโนมัติ

## ฮาร์ดแวร์ที่ต้องใช้

### ไมโครคอนโทรลเลอร์
- **ESP32-S3-N16R8** (Flash 16MB, PSRAM 8MB)
- ตัวประมวลผล Dual-core ที่รัน FreeRTOS

### เซนเซอร์
- **MPU9250/MPU6500** - IMU 9 แกน (I2C: 0x68)
- **VL53L1X** - เซนเซอร์วัดระยะแบบ Time-of-Flight (I2C: 0x29)
- **GPS Module** - รองรับ NEO-6M/7M/8M (UART: 9600 baud)
- **SH1106** - จอ OLED 128x64 (I2C: 0x3C)

### Actuators
- เซอร์โวมอเตอร์ 4 ตัว สำหรับครีบควบคุมทิศทาง
- มอเตอร์ brushless 1 ตัว พร้อม ESC สำหรับแรงขับหลัก

### การกำหนด Pin
```cpp
// I2C Bus
#define I2C_SDA 8
#define I2C_SCL 9

// GPS UART
#define GPS_RX_PIN 17
#define GPS_TX_PIN 18

// Servo/ESC PWM Pins
PIN_1 = 1   // ครีบด้านหน้า (Front)
PIN_2 = 15  // ครีบด้านขวา (Right)
PIN_3 = 2   // ครีบด้านซ้าย (Left)
PIN_4 = 16  // ครีบด้านหลัง (Back)
PIN_5 = 39  // มอเตอร์ขับหลัก (Thruster ESC)

// Status LED
#define RGB_LED_PIN 48  // LED WS2812 ในบอร์ด
```

## สถาปัตยกรรมซอฟต์แวร์

### การกระจายงานแบบ Dual-Core

#### **Core 0** - การควบคุมแบบ Real-time (Priority: 3, 100Hz)
- อ่านข้อมูลและผสาน IMU
- ประมาณค่าสถานะด้วย Kalman filter
- คำนวณการควบคุม
- ส่งสัญญาณไปยังเซอร์โวและมอเตอร์

#### **Core 1** - การสื่อสารและ UI (Priority: 1-2)
- micro-ROS publisher (ส่งข้อมูล GPS/IMU)
- ประมวลผลข้อมูล GPS @ 10Hz
- อัปเดตจอ OLED @ 2Hz
- จัดการการเชื่อมต่อ WiFi

### โมดูลหลัก

| โมดูล | ไฟล์ | คำอธิบาย |
|---|---|---|
| **IMU Handler** | `imu.cpp/h` | อ่านข้อมูล MPU9250, แปลงพิกัด, คำนวณมุม |
| **Actuator Control** | `Actuator.cpp/h` | ควบคุมเซอร์โว/ESC พร้อมคำสั่ง Serial |
| **Kalman Filter** | `kalman.cpp/h` | ประมาณค่าและทำนายสถานะ |
| **LQR Controller** | `lqr_hover.cpp/h` | เมทริกซ์ค่า Gain สำหรับควบคุมแบบ optimal |
| **GPS Handler** | `gps_handler.cpp/h` | แปลงและจัดการข้อมูล GPS |
| **ToF Sensor** | `Tof.cpp/h` | วัดความสูงด้วย VL53L1X |
| **micro-ROS** | `microros_handler.cpp/h` | ติดต่อสื่อสารกับ ROS2 |
| **WiFi Manager** | `wifi_manager.cpp/h` | จัดการการเชื่อมต่อ WiFi |
| **OLED Display** | `oled_display.cpp/h` | แสดงสถานะแบบหลายหน้า |
| **LED Status** | `led_status.cpp/h` | แสดงสถานะด้วย LED RGB |

## ฟีเจอร์หลัก

### 1. การจัดการพิกัด IMU

ระบบรองรับ**หลายแนวการติดตั้ง IMU**:

```cpp
typedef enum {
    ROTATION_0,           // แกน X ชี้หน้า (มาตรฐาน PCB)
    ROTATION_90_CW,       // แกน Y ชี้หน้า
    ROTATION_90_CCW,      // แกน -Y ชี้หน้า
    ROTATION_180,         // แกน -X ชี้หน้า
    ROTATION_UPSIDE_DOWN, // กลับหัวกลับหาง
    ROTATION_CUSTOM_1-6   // การติดตั้งแบบขอบ
} IMU_ROTATION;
```

**ฟังก์ชัน Auto-calibration**:
```cpp
imu.testAllRotationsComplete();  // ทดสอบทั้ง 11 แบบ
imu.setRotation(ROTATION_CUSTOM_3);  // ใช้แบบที่เหมาะสมที่สุด
imu.zeroOrientation();  // ตั้งค่าศูนย์ที่ท่าปัจจุบัน
```

### 2. ระบบควบคุม Actuator

**คำสั่งผ่าน Serial**:
```
center              → รีเซ็ตเซอร์โวทั้งหมดกลับจุดกลาง
1 <-10~10>         → ออฟเซ็ตครีบหน้า
2 <-10~10>         → ออฟเซ็ตครีบขวา
3 <-10~10>         → ออฟเซ็ตครีบซ้าย
4 <-10~10>         → ออฟเซ็ตครีบหลัง
5 <0~100>          → กำลังมอเตอร์ %
all <offset>       → ตั้งค่าครีบทั้งหมดพร้อมกัน
set <1> <2> <3> <4> → ตั้งค่าครีบแต่ละตัว
stop               → หยุดฉุกเฉินมอเตอร์
status             → แสดงตำแหน่งปัจจุบัน
```

**การใช้งานในโค้ด**:
```cpp
ROVController rov;
rov.begin();           // เริ่มต้นเซอร์โวและ ESC
rov.setServo(1, 5);    // ครีบหน้า +5°
rov.setThruster(50);   // ใช้กำลัง 50%
rov.moveToCenter();    // กลับจุดกลาง
rov.stop();            // หยุดฉุกเฉิน
```

### 3. การประมาณค่าสถานะ (Kalman Filter)

**State Vector 12 ตัว**:
```
x = [roll, pitch, yaw, wx, wy, wz, x, y, z, vx, vy, vz]
```

**Input Vector 5 ตัว**:
```
u = [alpha1, alpha2, alpha3, alpha4, motor_rpm]
```

**การใช้งาน**:
```cpp
DroneModel Tewadon;
DroneParams p;
// ... ตั้งค่าพารามิเตอร์ ...
Tewadon.setParams(p);

// ขั้นตอนทำนาย
Tewadon.computeContinuousModel(hover_thrust, hover_rpm);
Tewadon.discretize(0.01);  // dt = 10ms
Tewadon.predictState(state_est, control_input, state_pred);

// ขั้นตอนอัปเดต
Tewadon.updateStateWithMeasurements(state_pred, measurement, state_est);
```

### 4. การสื่อสารด้วย micro-ROS

**การตั้งค่า(ตั้งค่าตามอุปกรณ์นั้นๆ)**:
```cpp
MicroROSConfig ros_config = {
    .agent_ip = "172.20.10.2",
    .agent_port = 8888,
    .node_name = "esp32_node",
    .topic_name = "esp32_s3_Drone",
    .domain_id = 42,
    .timer_timeout_ms = 10
};
```

**ประเภทข้อความที่ Publish**: `sensor_msgs/NavSatFix`
```cpp
Pungapond.latitude = getGPSData().latitude;
Pungapond.longitude = getGPSData().longitude;
Pungapond.altitude = getGPSData().altitude;
```

### 5. ตัวบอกสถานะด้วย LED

| สี | สถานะ |
|-----|---|
| 🔴 แดง | WiFi ไม่เชื่อมต่อ |
| 🟡 เหลือง | กำลังเชื่อมต่อ WiFi |
| 🟢 เขียว | WiFi เชื่อมต่อแล้ว, ROS ยังไม่เชื่อมต่อ |
| 🔵 น้ำเงิน | กำลังเชื่อมต่อ ROS Agent |
| 🟣 ม่วง | เชื่อมต่อครบและกำลังส่งข้อมูล |
| 🟠 ส้ม | กำลังเชื่อมต่อใหม่ |

```cpp
initLED();
updateStatusLED(wifi_connected, agent_connected, publishing);
```

### 6. จอแสดงผลแบบหลายหน้า

**สามหน้าจอ** (สลับอัตโนมัติทุก 5 วินาที):

**หน้า 0 - ข้อมูล GPS**:
```
=== GPS DATA ===
SAT: 8 LOCKED
Lat: 13.651234
Lon: 100.494321
Alt: 45.2m
Spd: 0.0km/h
```

**หน้า 1 - สถานะ WiFi**:
```
=== WiFi INFO ===
Status: CONNECTED
SSID: iPhone
ROS Agent: OK
```

**หน้า 2 - ข้อมูลตำแหน่ง**:
```
=== POSITION ===
GPS: 8 LOCK
```

## การ Build และ Flash

### PlatformIO (แนะนำ)
```bash
# ติดตั้ง dependencies
pio lib install

# Build
pio run

# Upload
pio run --target upload

# ดู Serial Monitor
pio device monitor
```

### Arduino IDE
1. ติดตั้ง ESP32 board support (v2.0.8+)
2. ติดตั้งไลบรารีที่ต้องใช้:
   - `micro_ros_arduino`
   - `ESP32Servo`
   - `Adafruit_SH110X`
   - `Adafruit_NeoPixel`
   - `Adafruit_VL53L1X`
   - `TinyGPSPlus`

3. เลือกบอร์ด **ESP32S3 Dev Module**:
   - Flash Size: 16MB
   - PSRAM: OPI PSRAM
   - Upload Speed: 921600

4. Compile และ upload `main.cpp`

## ขั้นตอนการเริ่มระบบ

1. ✅ เริ่มต้น I2C Bus (SDA=8, SCL=9)
2. ✅ สอบเทียบ IMU - ตรวจหาแนวการติดตั้งอัตโนมัติ
3. ✅ Arming เซอร์โว/ESC - สอบเทียบ ESC 3 วินาที
4. ✅ เชื่อมต่อ WiFi - เชื่อมต่อกับ Access Point
5. ✅ ค้นหา micro-ROS Agent - ลองจนกว่าจะเชื่อมต่อได้
6. ✅ สร้าง FreeRTOS Tasks:
   - Core 0: วงควบคุม IMU @ 100Hz
   - Core 1: ROS Publisher, GPS, Display
7. 🚁 พร้อมบิน

## ไฟล์การตั้งค่า

### ตั้งค่า WiFi & ROS (`main.cpp`)
```cpp
char WIFI_SSID[] = "ชื่อ WiFi ของคุณ";
char WIFI_PASSWORD[] = "รหัสผ่าน";

MicroROSConfig ros_config = {
    .agent_ip = "192.168.1.100",  // IP ของคอมพิวเตอร์
    .agent_port = 8888,
    .node_name = "esp32_node",
    .topic_name = "esp32_s3_Drone",
    .domain_id = 42
};
```

### ตั้งค่าแนว IMU
```cpp
// ใน setup():
imu.setRotation(ROTATION_CUSTOM_0);  // เปลี่ยนตามการติดตั้ง
imu.zeroOrientation();  // ตั้งศูนย์บนพื้นราบ
```

### ตำแหน่งกลางเซอร์โว
```cpp
// ปรับถ้าเซอร์โวไม่อยู่กึ่งกลาง:
rov.setCenterPositions(70, 71, 64, 73);
```

## การแก้ปัญหา

### ตรวจไม่พบ IMU
```
WHO_AM_I: 0xFF
❌ WHO_AM_I does not match MPU series!
```
**วิธีแก้**: ตรวจสอบสาย I2C (SDA=8, SCL=9) และยืนยันแอดเดรส 0x68

### Roll/Pitch ผิดตอนวางราบ
```
Roll: -45.2°  Pitch: 12.8°
```
**วิธีแก้**: 
```cpp
imu.testAllRotationsComplete();  // หาแนวที่ถูกต้อง
imu.setRotation(ROTATION_CUSTOM_3);  // ใช้แนวที่เหมาะสม
```

### ESC ไม่ทำงาน (ไม่มีเสียงบี๊บ)
```
⚠️ Setting up Thruster ESC...
(ไม่มีเสียงจาก ESC)
```
**วิธีแก้**: 
- ตรวจสอบสัญญาณ PWM ที่ GPIO 39
- ตรวจแรงดันแบตเตอรี่ > 11.1V
- ลอง `rov.setThruster(0)` แล้วค่อยเพิ่มทีละน้อย

### เชื่อมต่อ micro-ROS ไม่ได้
```
Agent connection timeout!
```
**วิธีแก้**:
```bash
# บนคอมพิวเตอร์ เปิด ROS2 agent:
ros2 run micro_ros_agent micro_ros_agent udp4 --port 8888

# ตรวจสอบเครือข่าย:
ping 172.20.10.2
```

### GPS หาสัญญาณไม่เจอ
```
SAT: 0 NO SIG
```
**วิธีแก้**:
- ย้ายไปที่แจ้งมองเห็นท้องฟ้า
- รอ 2-5 นาทีสำหรับ cold start
- ตรวจสอบสาย: TX→GPIO17, RX→GPIO18

## API Reference

### ฟังก์ชัน IMU
```cpp
imu.begin()                          // เริ่มต้นเซนเซอร์
imu.readSensorData()                 // อ่านข้อมูลดิบ
imu.calculateOrientation()           // คำนวณ roll/pitch/yaw
imu.setRotation(ROTATION_MODE)       // ตั้งค่าพิกัด
imu.zeroOrientation()                // ตั้งศูนย์ที่ท่าปัจจุบัน
imu.testAllRotationsComplete()       // หาแนวที่ดีที่สุดอัตโนมัติ
```

### ฟังก์ชัน Actuator
```cpp
rov.begin()                          // เริ่มต้นเซอร์โวทั้งหมด
rov.setServo(num, offset)            // num: 1-4, offset: -10 ถึง 10
rov.setThruster(power)               // power: 0-100
rov.setAllServos(offset)             // ตั้งครีบทั้งหมดเท่ากัน
rov.moveToCenter()                   // กลับจุดกลาง
rov.stop()                           // หยุดฉุกเฉินมอเตอร์
rov.update()                         // เรียกใน loop() - จัดการ serial และเคลื่อนที่นุ่มนวล
```

### ฟังก์ชัน GPS
```cpp
initGPS(rx_pin, tx_pin, baud)        // เริ่มต้นโมดูล GPS
updateGPS()                          // ประมวลผลข้อมูลเข้า
GPSData data = getGPSData()          // รับตำแหน่งปัจจุบัน
printGPSData()                       // Debug output
testGPSConnection()                  // ตรวจสอบสถานะ GPS
```

### ฟังก์ชันจอแสดงผล
```cpp
initDisplay()                        // เริ่มต้น OLED
displayGPSPage()                     // แสดงข้อมูล GPS
displayWiFiPage(ssid, wifi, ros)     // แสดงสถานะการเชื่อมต่อ
switchDisplayPage()                  // สลับหน้าจอ
showMessage(line1, line2, line3)     // ข้อความกำหนดเอง
```

### ฟังก์ชัน LED
```cpp
initLED()                            // เริ่มต้น RGB LED
setLED(color)                        // ตั้งสีเฉพาะ
updateStatusLED(wifi, ros, pub)      // แสดงสถานะอัตโนมัติ
blinkLED(color, times, duration)     // กระพริบ
```

## ประสิทธิภาพระบบ

| ตัวชี้วัด | ค่า |
|---|-----|
| อัตราอัปเดต IMU | 100 Hz |
| ความหน่วงวงควบคุม | <10 ms |
| อัตรา Publish ROS | 100 Hz |
| อัตราอัปเดต GPS | 1 Hz |
| Refresh จอแสดงผล | 2 Hz |

## 🎯 Expected Results
### Performance Targets

1. **การควบคุมท่าทาง (Attitude Control)**
   - สามารถควบคุมโดรนให้ควบคุมองศาของตัวเองได้
   - **Target Error:** ≤ ±10 degrees (Roll, Pitch, Yaw)

2. **การควบคุมความสูง (Altitude Control)**  
   - ตัวโดรนสามารถรักษาตำแหน่งความสูงที่กำหนดให้ได้
   - **Target Error:** ≤ ±5 cm

3. **การทรงตัว (Hovering Capability)**
   - โดรนสามารถลอยตัวได้ด้วยการควบคุมแบบ Thrust Vectoring
   - เสถียรภาพในการลอยตัวด้วยตนเอง

4. **ประสิทธิภาพการสื่อสาร (Communication Performance)**
   - การสื่อสาร ROS2 ↔ MicroROS มีความเสถียรและหน่วงต่ำ
   - Latency < 50ms สำหรับ critical commands

5. **ความทนทานต่อสิ่งรบกวน (Disturbance Rejection)**
   - LQR สามารถรักษาสมดุลของโดรนได้ภายใต้ disturbance ขนาดเล็ก
   - การตอบสนองต่อลมเบา ๆ หรือการเปลี่ยนแปลงโหลด

6. **การแสดงผลแบบเรียลไทม์ (Real-time Visualization)**
   - แสดงทิศทางแรงขับและท่าทางของโดรนใน Rviz ได้อย่างถูกต้อง
   - การมอนิเตอร์สถานะแบบเรียลไทม์

## 📅 Project Timeline

### Development Schedule (6 Weeks)

| Week | Tasks | Deliverables | Status |
|---|---|---|---|
| **Week 1** | ออกแบบโครงสร้างและระบบของโดรน<br>• Frame design<br>• Motor & ESC selection<br>• Flight controller planning | • CAD models<br>• Component list<br>• System architecture | ✅ Complete |
| **Week 2** | ติดตั้งและตั้งค่า MicroROS บน ESP32<br>• ESP32 firmware development<br>• ROS2 setup on PC | • Working MicroROS node<br>• Basic communication test | ✅ Complete |
| **Week 3** | พัฒนา Communication Code<br>• WiFi communication<br>• Topic structure<br>• Message protocols | • Stable MicroROS ↔ ROS2 link<br>• Real-time data exchange | ✅ Complete |
| **Week 4** | พัฒนาระบบควบคุมการบินเบื้องต้น<br>• LQR implementation<br>• Node/Topic/Service structure | • Flight control nodes<br>• Basic control algorithms | ✅ Complete |
| **Week 5** | ทดสอบการส่งข้อมูล Sensor จาก Micro ROS ไปยัง ROS2 และทดสอบบินจริงเพื่อปรับจูนพารามิเตอร์ <br>• Sensor integration testing<br>• LQR tuning<br>• Real flight tests | • Tuned parameters<br>• Flight test results<br>• Performance validation | 🔄 In Progress |

### Current Milestone Status

## 🎯 Current Focus: Week 5 
1. ทดสอบการส่งข้อมูล Sensor ผ่าน MicroROS → ROS2
2. ทดสอบบินจริงและปรับจูน LQR parameters

---

## 💻 Installation & Setup

### Prerequisites

**Hardware Requirements:**
- Drone hardware with flight controller
- WiFi module for communication
- Sensors: IMU, GPS, TOF, OLED
- 4x Servos + ESC + Ducted fan

**Software Requirements:**
- Ubuntu 22.04 (Jammy)
- ROS2 Humble
- Python 3.10+
- Gazebo (for simulation)

### Installation Steps

#### 1. Install ROS2 Humble

```bash
# Setup sources
sudo apt update && sudo apt install locales
sudo locale-gen en_US en_US.UTF-8
sudo update-locale LC_ALL=en_US.UTF-8 LANG=en_US.UTF-8
export LANG=en_US.UTF-8

# Setup ROS2 repository
sudo apt install software-properties-common
sudo add-apt-repository universe
sudo apt update && sudo apt install curl -y
sudo curl -sSL https://raw.githubusercontent.com/ros/rosdistro/master/ros.key -o /usr/share/keyrings/ros-archive-keyring.gpg
echo "deb [arch=$(dpkg --print-architecture) signed-by=/usr/share/keyrings/ros-archive-keyring.gpg] http://packages.ros.org/ros2/ubuntu $(. /etc/os-release && echo $UBUNTU_CODENAME) main" | sudo tee /etc/apt/sources.list.d/ros2.list > /dev/null

# Install ROS2 Humble
sudo apt update
sudo apt install ros-humble-desktop
```

#### 2. Install Dependencies

```bash
# ROS2 packages
sudo apt install ros-humble-gazebo-ros-pkgs
sudo apt install ros-humble-gazebo-plugins
sudo apt install ros-humble-rviz2
sudo apt install ros-humble-robot-state-publisher
sudo apt install ros-humble-joint-state-publisher
sudo apt install ros-humble-teleop-twist-keyboard

# MicroROS Agent (for real hardware)
sudo apt install ros-humble-micro-ros-agent

# Python packages
pip install numpy scipy matplotlib
pip install pyserial
```

#### 3. Clone and Build Workspace

```bash
# Clone repository
git clone --branch Project https://github.com/PPHUSIN/FRA502-LAB-6645.git
cd FRA502-LAB-6645/

# Build workspace
colcon build

# Source workspace
source install/setup.bash
```

#### 4. Configure Network (Real Hardware Only)

**On Drone (ESP32 Client):**
```cpp
// In ESP32 firmware
#define WIFI_SSID "your_wifi_ssid"
#define WIFI_PASSWORD "your_wifi_password"
#define AGENT_IP "192.168.1.xxx"  // PC IP address
#define AGENT_PORT 8888
```

**On PC (Agent):**
```bash
# Set ROS_DOMAIN_ID
echo "export ROS_DOMAIN_ID=0" >> ~/.bashrc

# Set RMW implementation
echo "export RMW_IMPLEMENTATION=rmw_cyclonedds_cpp" >> ~/.bashrc

source ~/.bashrc
```

---

## 🎯 Usage

### 🖥️ Running Simulation Mode

```bash
# Terminal 1: Launch Gazebo simulation
source install/setup.bash
ros2 launch drone_gazebo simulation_launch.py
```

```bash
# Terminal 2: Launch Rviz
source install/setup.bash
ros2 launch drone drone.launch.py
```

```bash
# Terminal 3: Select Comtrol Mode
source install/setup.bash
ros2 topic pub /drone/control_mode std_msgs/msg/String "data: 'POSITION'" --once 
ros2 topic pub /drone/control_mode std_msgs/msg/String "data: 'VELOCITY'" --once 
```

```bash
# Terminal 4: Setpoint Position
source install/setup.bash
ros2 topic pub /drone/setpoint geometry_msgs/msg/Twist "linear:
  x: 1.0
  y: 1.0
  z: 2.0
angular:
  x: 0.0
  y: 0.0
  z: 0.0" --once
```

```bash
# Terminal 5: Setpoint Velocity
source install/setup.bash
ros2 topic pub /drone/velocity_setpoint geometry_msgs/msg/Vector3 "x: 2.0
y: 1.0
z: 2.0" --once 
```

```bash
# Terminal 6: Teleop Setpoint Velocity in Simulation
source install/setup.bash
ros2 run drone teleop_sim.py
```

### Control Commands (Velocity Setpoint)

**🖥️ Simulation Teleop (teleop_sim.py):**
```
Velocity Setpoint (World Frame):
   w : +X (Forward)     speed = 1.0 m/s
   s : -X (Backward)
   a : +Y (Left)
   d : -Y (Right)
   space : +Z (Up)
   c : -Z (Down)
   CTRL-C : Quit
```

**🚁 Real Hardware Teleop (teleop.py):**
```
Velocity Setpoint (Body Drone Frame):
   w : +X (Forward)     speed = 0.1 m/s (ช้ากว่าเพื่อความปลอดภัย)
   s : -X (Backward)
   a : +Y (Left)
   d : -Y (Right)
   space : +Z (Up)
   c : -Z (Down)
   CTRL-C : Quit
```

---

## 📚 References

1. **Master Thesis - Emil Jacobsen**
   - "Vectored Thrust Aided Attitude Control for a Single Rotor UAV"
   - https://vbn.aau.dk/ws/files/421577367/Master_Thesis_Emil_Jacobsen_v5.pdf

2. **Thrust Vectoring Control for Heavy UAVs**
   - Isaac, M. S. A., Ragab, A. R., Luna, M. A., Ale Eshagh Khoeini, M. M., & Campoy, P. (2023)
   - Employing a Redundant Communication

3. **Valle et al. (2024)**
   - การพัฒนาระบบควบคุมแรงขับแบบเบี่ยงทิศ (thrust vectoring) สำหรับ Heavy UAVs
   - การบูรณาการระหว่างเซนเซอร์ IMU เข้ากับระบบควบคุมแบบป้อนกลับ

4. **ROS2 Documentation**
   - https://docs.ros.org/en/humble/

5. **MicroROS Documentation**
   - https://micro.ros.org/

---

## 👥 Team

**FIBO FRA502 – RoboticsDev Final Project 2025**
**Institute of Field Robotics, King Mongkut's University of Technology Thonburi**

**Project Members:**
- **คุณานนต์ เศวตคชกุล** (66340500006) 
- **นาราชล นรากุลพัชร์** (66340500027) 
- **ภูษิญ ประเสริฐสม** (66340500045) 
- **วิชาญ วิชญานุภาพ** (66340500051) 
- **ปวริศ ตั้งตระกูล** (66340500074) 

**Institution:**
- Institute of Field Robotics
- King Mongkut's University of Technology Thonburi  
- 126 Pracha Uthit Rd, Bang Mot, Thung Khru, Bangkok, Thailand 10140

---

## 📝 License

This project is developed as part of FIBO FRA502 RoboticsDev coursework.
Copyright © 2025 by FIBO, KMUTT

---

## 🙏 Acknowledgments

- **ROS2 Community** for the excellent robotics framework
- **MicroROS Team** for embedded ROS2 support
- **Emil Jacobsen** for the foundational thesis on thrust vectoring control
- **FIBO Faculty** and **KMUTT** for project support and facilities
- **Valle et al.** for inspiration from thrust vectoring research

---

## 📧 Contact

**For questions or collaboration:**
- **Institution:** Institute of Field Robotics, KMUTT
- **Course:** FIBO FRA502 – RoboticsDev Final Project 2025
- **Location:** Bangkok, Thailand

---

**Project Status:** 🔄 **Week 5 - Development in Progress (integrate and Flight Test)**  
**Last Updated:** 06 December, 2025

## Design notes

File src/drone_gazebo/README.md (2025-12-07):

# TVC Drone Simulation with LQR Control

A comprehensive ROS2 simulation of a thrust vector control (TVC) drone with aerodynamic fins and advanced LQR-based control systems. This project implements a unique drone design using four aerodynamic control fins for attitude control instead of traditional rotor speed differential.

## System Overview

This simulation models a novel drone configuration where:
- **Propulsion**: Single thrust source for vertical lift
- **Control**: Four aerodynamic fins provide roll, pitch, and yaw control
- **Control System**: Dual-loop LQR controllers for attitude and position control
- **Modes**: Position and velocity control capabilities

## Architecture

### Control System Hierarchy
```
┌─────────────────────────────────────────────────────────────────────┐
│                          Position Controller                         │
│  ┌─────────────────┐    ┌─────────────────┐    ┌─────────────────┐  │
│  │   Position      │    │    Velocity     │    │     Goal        │  │
│  │     Mode        │    │      Mode       │    │   Commands      │  │
│  └─────────────────┘    └─────────────────┘    └─────────────────┘  │
│                                │                                     │
│                         Position Setpoints                          │
└─────────────────────────────────┼───────────────────────────────────┘
                                  │
┌─────────────────────────────────┼───────────────────────────────────┐
│                        Attitude Controller                          │
│  ┌─────────────────────────────────────────────────────────────┐    │
│  │                    LQR Hover Control                       │    │
│  │  [Roll, Pitch, Yaw, ω_x, ω_y, ω_z, Z, Z_dot, Z_integral] │    │
│  └─────────────────────────────────────────────────────────────┘    │
│                                │                                     │
│                           Fin Commands                              │
└─────────────────────────────────┼───────────────────────────────────┘
                                  │
┌─────────────────────────────────┼───────────────────────────────────┐
│                         TVC Aerodynamics                            │
│  ┌─────────┐  ┌─────────┐  ┌─────────┐  ┌─────────┐  ┌─────────┐   │
│  │  Fin 1  │  │  Fin 2  │  │  Fin 3  │  │  Fin 4  │  │ Thrust  │   │
│  │ (Front) │  │ (Back)  │  │ (Left)  │  │ (Right) │  │         │   │
│  └─────────┘  └─────────┘  └─────────┘  └─────────┘  └─────────┘   │
│                                │                                     │
│                       Forces & Torques                              │
└─────────────────────────────────┼───────────────────────────────────┘
                                  │
                              Gazebo Physics
```

## Component Details

### 1. Launch System (`simulation_launch.py`)
**Purpose**: Orchestrates the complete simulation environment

**Features**:
- Gazebo world setup with aerodynamics environment
- URDF/XACRO robot model processing
- Multi-node launch coordination
- Robot state publisher initialization

**Key Components Launched**:
- Gazebo simulation environment
- Robot state publisher
- Drone entity spawner
- TVC controller node
- LQR controller node

### 2. LQR Gain Calculation (`find_lqr.py`)
**Purpose**: Computes optimal control gains using Linear Quadratic Regulator theory

**Physical Parameters**:
```python
# Drone Configuration
MASS = 0.707 kg                    # Total drone mass
Ixx, Iyy = 0.01 kg⋅m²            # Roll/Pitch inertia
Izz = 0.02 kg⋅m²                  # Yaw inertia
L_VERT = 0.048 m                  # Vertical arm length
L_HORZ = 0.029 m                  # Horizontal arm length

# Aerodynamic Configuration
D_PROP = 0.07 m                   # Propeller diameter (7cm)
FIN_SPAN = 0.125 m                # Fin span (12.5cm)
FIN_CHORD = 0.060 m               # Fin chord (6cm)
CL_alpha = 6.18 rad⁻¹             # Lift curve slope
```

**Control Matrices**:
- **Hover Control**: 9-state system (attitude + altitude)
- **Position Control**: 6-state system (position + velocity)
- **Weighting**: Optimized for stability and response time

### 3. LQR Controller Node (`lqr_node.py`)
**Purpose**: Real-time control system implementing dual-mode operation

#### Control Modes

**Position Mode**:
- Direct position setpoint tracking
- Immediate goal following
- Traditional waypoint navigation

**Velocity Mode**:
- Continuous velocity command integration
- Moving position target generation
- Suitable for teleoperation or trajectory following

#### State Vectors

**Hover State** (9 elements):
```python
[roll, pitch, yaw, ω_x, ω_y, ω_z, z, z_dot, z_integral]
```

**Position State** (6 elements):
```python
[x, y, x_dot, y_dot, unused, unused]
```

#### ROS2 Interface

**Publishers**:
- `/drone/fin_1/position` → `/drone/fin_4/position`: Fin angle commands
- `/drone/cmd_thrust`: Thrust command
- `/drone/control_status`: System status

**Subscribers**:
- `/odom`: Vehicle odometry
- `/drone/goal`: Position goals (Position mode)
- `/drone/setpoint`: Direct setpoints
- `/drone/velocity_setpoint`: Velocity commands (Velocity mode)
- `/drone/control_mode`: Mode switching commands

### 4. TVC Aerodynamics Controller (`tvc_controller.py`)
**Purpose**: Converts fin deflections to aerodynamic forces and torques

#### Aerodynamic Model

**Momentum Theory**: Propeller-induced dynamic pressure
```python
q = 0.5 * ρ * v_exit²
where v_exit² = Thrust / (ρ * A_disk)
```

**Fin Force Generation**:
```python
Lift = q * A_fin * CL_alpha * angle
```

#### Fin-to-Control Mapping

| Fin | Position | Primary Control | Secondary Effect |
|-----|---|---|---|
| Fin 1 | Front (X+) | Roll Control | Yaw Coupling |
| Fin 2 | Back (X-) | Roll Control | Yaw Coupling |
| Fin 3 | Left (Y+) | Pitch Control | Yaw Coupling |
| Fin 4 | Right (Y-) | Pitch Control | Yaw Coupling |

**Force/Torque Distribution**:
- **Roll Torque**: τ_x = ±F_lift × L_vert (Fins 1,2)
- **Pitch Torque**: τ_y = ±F_lift × L_vert (Fins 3,4)
- **Yaw Torque**: τ_z = -F_lift × L_horz (All fins)

## Technical Specifications

### Performance Characteristics
- **Control Frequency**: 100 Hz
- **Maximum Tilt Angle**: ±8.6° (±0.15 rad)
- **Fin Deflection Limit**: ±8.6° (±0.15 rad)
- **Thrust Range**: 0-120 N
- **Position Accuracy**: ~2cm steady-state
- **Response Time**: <0.5s for attitude, <2s for position

## Gain Tuning Guidelines

### LQR Weight Matrix Tuning

**Hover Control Weights** (`Q_hov`):
```python
Q_hov = np.diag([200., 200., 20., 10., 10., 10., 3., 2., 1.])
#               [roll pitch yaw  ωx   ωy   ωz   z  z_dot z_int]
```

**Position Control Weights** (`Q_pos`):
```python
Q_pos = np.diag([1.0, 1.0, 1.8, 1.8])
#               [x    y    x_dot y_dot]
```

**Control Effort Weights** (`R`):
```python
R_hov = np.diag([1., 1., 1., 1., 0.8])  # [fin1, fin2, fin3, fin4, thrust]
R_pos = np.eye(2) * 1.0                 # [roll_cmd, pitch_cmd]
```

### Tuning Strategy
1. **Increase Position Weights**: Faster position response, potential overshoot
2. **Increase Attitude Weights**: Stiffer attitude control, better disturbance rejection
3. **Increase Control Weights**: Smoother control, slower response
4. **Decrease Integral Weight**: Faster altitude response, potential steady-state error

## Troubleshooting

### Common Issues

**Oscillations in Attitude**:
- Check fin deflection limits (reduce if needed)
- Verify aerodynamic parameters
- Reduce attitude control weights

**Poor Position Tracking**:
- Verify coordinate frame alignment
- Check position control gains
- Monitor velocity feedback

**Simulation Instability**:
- Reduce control frequency if needed
- Check URDF inertial properties
- Verify Gazebo physics timestep

### Debug Topics
```bash
# Monitor fin commands
ros2 topic echo /drone/fin_1/position

# Check thrust commands  
ros2 topic echo /drone/cmd_thrust

# View applied forces/torques
ros2 topic echo /drone/thrust

# System diagnostics
ros2 topic echo /drone/control_status
```

## License

This project is part of ongoing robotics research at King Mongkut's University of Technology Thonburi (KMUTT).

## Citation

If you use this simulation in your research, please cite:
```
@misc{tvc_drone_sim_2024,
  title={TVC Drone Simulation with LQR Control},
  author={Pao},
  institution={King Mongkut's University of Technology Thonburi},
  year={2024},
  note={Robotics and Control Systems Research}
}
```

---

**Contact**: For technical questions or collaboration opportunities, please reach out through academic channels.

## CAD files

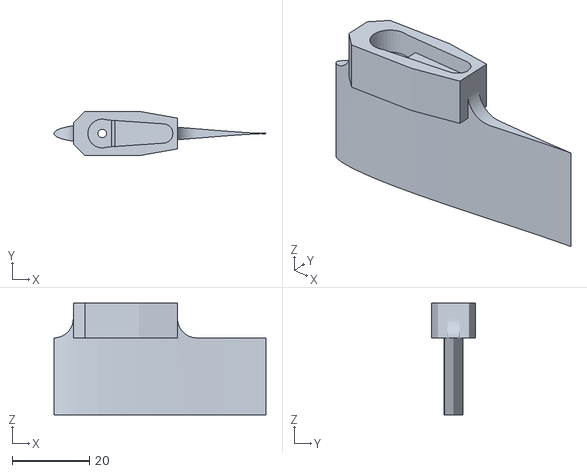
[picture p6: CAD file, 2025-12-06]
src/drone_gazebo/component/fin_2.stl
54.9 x 11.5 x 29.0

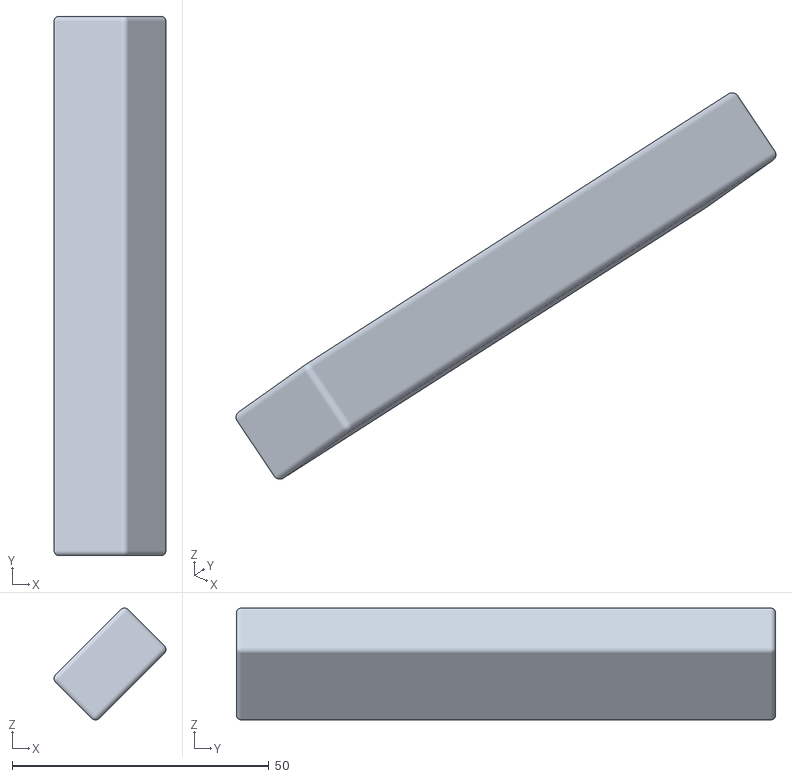
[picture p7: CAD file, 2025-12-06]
src/drone_gazebo/component/body.stl
21.8 x 105.0 x 21.8

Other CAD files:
src/drone_gazebo/component/fin_1.stl
src/drone_gazebo/component/fin_3.stl
src/drone_gazebo/component/fin_4.stl

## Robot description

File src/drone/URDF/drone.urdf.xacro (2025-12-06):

<?xml version="1.0"?>
<robot xmlns:xacro="http://www.ros.org/wiki/xacro" name="Thrut_Vectoring_Drone">

    <link name="base_link">
    </link>

    <joint name="base_to_body_joint" type="fixed">
        <parent link="base_link"/>
        <child link="body_drone"/>
        <origin xyz="0 0 0" rpy="0 0 0"/>
    </joint>

    <material name="black">
        <color rgba="1.0 1.0 1.0 1.0"/>
    </material>
    <material name="red">
        <color rgba="0.8 0.0 0.0 1.0"/>
    </material>

    <link name="body_drone">
        <visual>
        <origin xyz="-0.0625 0.0625 0.0" rpy="1.5708 0 0"/>
            <geometry>
                <mesh filename="package://drone/component/drviz.stl" scale="0.001 0.001 0.001"/>
            </geometry>
            <material name="red"/>
        </visual>        
    </link>

    <link name="fin_1">
        <visual>
            <origin xyz="-0.0116 -0.00575 -0.025" rpy="0 0 0"/> 
            <geometry>
                <mesh filename="package://drone/component/fin_1.stl" scale="0.001 0.001 0.001"/>
            </geometry> 
            <material name="black"/>           
        </visual>        
    </link>

    <joint name="fin_1_joint" type="revolute"> 
        <parent link="body_drone"/>
        <child link="fin_1"/>
        
        <origin xyz="0.0325 0.0 0.0425" rpy="0 1.5708 0"/>
        
        <axis xyz="0 0 1"/> 
        <limit lower="-1.57" upper="1.57" effort="10" velocity="10"/> 
    </joint>

    <link name="fin_2">
        <visual>
            <origin xyz="-0.0116 -0.00575 -0.025" rpy="0 0 0"/> 
            <geometry>
                <mesh filename="package://drone/component/fin_2.stl" scale="0.001 0.001 0.001"/>
            </geometry> 
            <material name="black"/> 
        </visual>        
    </link>

    <joint name="fin_2_joint" type="revolute"> 
        <parent link="body_drone"/>
        <child link="fin_2"/>
        
        <origin xyz="-0.0325 0.0 0.0425" rpy="0 1.5708 3.14"/>
        
        <axis xyz="0 0 1"/> 
        <limit lower="-1.57" upper="1.57" effort="10" velocity="10"/> 
    </joint>

    <link name="fin_3">
        <visual>
            <origin xyz="-0.0116 -0.00575 -0.025" rpy="0 0 0"/> 
            <geometry>
                <mesh filename="package://drone/component/fin_3.stl" scale="0.001 0.001 0.001"/>
            </geometry> 
            <material name="black"/>           
        </visual>        
    </link>

    <joint name="fin_3_joint" type="revolute"> 
        <parent link="body_drone"/>
        <child link="fin_3"/>
        
        <origin xyz="0.0 0.0325 0.0425" rpy="-1.5708 1.5708 0"/>
        
        <axis xyz="0 0 1"/> 
        <limit lower="-1.57" upper="1.57" effort="10" velocity="10"/> 
    </joint>

    <link name="fin_4">
        <visual>
            <origin xyz="-0.0116 -0.00575 -0.025" rpy="0 0 0"/> 
            <geometry>
                <mesh filename="package://drone/component/fin_4.stl" scale="0.001 0.001 0.001"/>
            </geometry> 
            <material name="black"/>           
        </visual>        
    </link>

    <joint name="fin_4_joint" type="revolute"> 
        <parent link="body_drone"/>
        <child link="fin_4"/>
        
        <origin xyz="0.0 -0.0325 0.0425" rpy="1.5708 1.5708 0"/>
        
        <axis xyz="0 0 1"/> 
        <limit lower="-1.57" upper="1.57" effort="10" velocity="10"/> 
    </joint>

</robot>

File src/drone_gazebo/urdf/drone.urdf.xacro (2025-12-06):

<?xml version="1.0"?>
<robot xmlns:xacro="http://www.ros.org/wiki/xacro" name="Thrut_Vectoring_Drone">

    <xacro:property name="body_mass" value="0.8"/>
    <xacro:property name="fin_mass" value="0.006"/>
    <xacro:property name="package_name" value="drone_gazebo"/>

    <xacro:macro name="box_inertia" params="m x y z">
        <inertial>
            <mass value="${m}"/>
            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
        </inertial>
    </xacro:macro>

    <link name="base_link"></link>

    <joint name="base_to_body_joint" type="fixed">
        <parent link="base_link"/>
        <child link="body_drone"/>
        <origin xyz="0 0 0" rpy="0 0 0"/>
    </joint>

    <link name="body_drone">
        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

        <inertial>
            <origin xyz="0 0 0" rpy="0 0 0"/>
            <mass value="${body_mass}"/>
            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
        </inertial>
    </link>

    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

    <link name="fin_1">
        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
        <xacro:box_inertia m="${fin_mass}" x="0.05" y="0.01" z="0.08"/>
    </link>

    <joint name="fin_1_joint" type="revolute">
        <parent link="body_drone"/>
        <child link="fin_1"/>
        <origin xyz="0.029 0.0 0.048" rpy="0 1.5708 0"/>
        <axis xyz="0 0 1"/>
        <limit lower="-1.57" upper="1.57" effort="10" velocity="10"/>
        <dynamics damping="0.1" friction="0.1"/>
    </joint>

    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

    <link name="fin_2">
        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
        <xacro:box_inertia m="${fin_mass}" x="0.05" y="0.01" z="0.08"/>
    </link>

    <joint name="fin_2_joint" type="revolute">
        <parent link="body_drone"/>
        <child link="fin_2"/>
        <origin xyz="-0.029 0.0 0.048" rpy="0 1.5708 3.14"/>
        <axis xyz="0 0 1"/>
        <limit lower="-1.57" upper="1.57" effort="10" velocity="10"/>
        <dynamics damping="0.1" friction="0.1"/>
    </joint>

    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

    <link name="fin_3">
        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
        <xacro:box_inertia m="${fin_mass}" x="0.05" y="0.01" z="0.08"/>
    </link>

    <joint name="fin_3_joint" type="revolute">
        <parent link="body_drone"/>
        <child link="fin_3"/>
        <origin xyz="0.0 0.029 0.048" rpy="-1.5708 1.5708 0"/>
        <axis xyz="0 0 1"/>
        <limit lower="-1.57" upper="1.57" effort="10" velocity="10"/>
        <dynamics damping="0.1" friction="0.1"/>
    </joint>

    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

    <link name="fin_4">
        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
        <xacro:box_inertia m="${fin_mass}" x="0.05" y="0.01" z="0.08"/>
    </link>

    <joint name="fin_4_joint" type="revolute">
        <parent link="body_drone"/>
        <child link="fin_4"/>
        <origin xyz="0.0 -0.029 0.048" rpy="1.5708 1.5708 0"/>
        <axis xyz="0 0 1"/>
        <limit lower="-1.57" upper="1.57" effort="10" velocity="10"/>
        <dynamics damping="0.1" friction="0.1"/>
    </joint>

    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

</robot>

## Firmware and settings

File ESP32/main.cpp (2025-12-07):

// #include <Arduino.h>
// #include <Wire.h>
// #include <Adafruit_GFX.h>
// #include <Adafruit_SH110X.h>
// #include "imu.h"
// #include "led_status.h"
// #include "wifi_manager.h"
// #include "microros_handler.h"
// #include "gps_handler.h"
// #include "oled_display.h"
// // #include "Controller.h"
// #include "Tof.h"
// #include "Actuator.h"
// #include "kalman.h"
// #include "lqr_hover.h"
// // ============================================
// // DUAL CORE CONFIGURATION
// // ============================================
// #define CORE_IMU_CONTROL 0  // Core 0: High-priority real-time tasks
// #define CORE_COMM_UI 1      // Core 1: Communication & UI tasks

// // Task handles
// TaskHandle_t taskIMUHandle = NULL;
// TaskHandle_t taskROSHandle = NULL;
// TaskHandle_t taskGPSHandle = NULL;
// TaskHandle_t taskDisplayHandle = NULL;

// // Mutex for shared resources
// SemaphoreHandle_t i2cMutex;
// SemaphoreHandle_t dataMutex;

// ROVController rov;

// // WiFi credentials
// char WIFI_SSID[] = "iPhone";
// char WIFI_PASSWORD[] = "phu27816234";

// // micro-ROS configuration
// MicroROSConfig ros_config = {
//     .agent_ip = (char*)"172.20.10.2",
//     .agent_port = 8888,
//     .node_name = (char*)"esp32_node",
//     .topic_name = (char*)"esp32_s3_Drone",
//     .domain_id = 42,
//     .timer_timeout_ms = 10
// };

// // GPS Configuration
// #define GPS_RX_PIN 17
// #define GPS_TX_PIN 18
// #define GPS_BAUD 9600

// // I2C Configuration
// #define I2C_SDA 8
// #define I2C_SCL 9

// // Global instances
// MPU9250_IMU imu;
// DroneModel Tewadon;
// DroneParams p; 
// // ThrustVectorController ctrl(&imu);  // Pass IMU pointer to controller
// // LQRController ctrl(&imu);

// // Connection states
// volatile bool wifi_connected = false;
// volatile bool agent_connected = false;

// extern uint8_t currentPage;

// float Altitude = 0.0;

// unsigned long last_time = 0;
// float state_est[STATE_DIM];    
// float state_pred[STATE_DIM];   
// float control_input[5];
// float measurement[6];

// // ตัวแปรสำหรับ LQR
// float Setpoint[9];
// float measurement_LQR[9];
// float control_output[5];
// void filter(){
//     measurement[0] = imu.getRoll() * (PI/180.0f);
//     measurement[1] = imu.getPitch() * (PI/180.0f);
//     measurement[2] = imu.getYaw() * (PI/180.0f); 
//     measurement[3] = 0.0;
//     measurement[4] = 0.0;
//     measurement[5] = 0.0;
//     float sim_rpm_for_model = (control_input[4] > 200.0f) ? control_input[4] : 200.0f;
//     Tewadon.computeContinuousModel(p.m * p.g, sim_rpm_for_model); 
//     Tewadon.discretize(0.01);
//     Tewadon.predictState(state_est, control_input, state_pred);
//     Tewadon.updateStateWithMeasurements(state_pred, measurement, state_est);
// }
// // ============================================
// // CORE 0: IMU & CONTROL TASK (Real-time Critical)
// // Priority: 3 (Highest)
// // Frequency: 100Hz
// // ============================================
// void taskIMUControl(void *parameter) {
//     Serial.println("🔥 Core 0: IMU & Control task started");
//     TickType_t xLastWakeTime = xTaskGetTickCount();
//     const TickType_t xFrequency = pdMS_TO_TICKS(10); // 100Hz
    
//     while(1) {
//         // Critical: IMU reading with I2C mutex
//         if (xSemaphoreTake(i2cMutex, pdMS_TO_TICKS(5)) == pdTRUE) {
//             imu.readSensorData();      // อ่านและแปลงแกนอัตโนมัติ
//             imu.calculateOrientation(); // คำนวณ Roll, Pitch, Yaw
//             // Altitude = ReadAltitude();
//             filter();
//             Altitude = 0;
//             xSemaphoreGive(i2cMutex);
//         }
        
//         // Debug print (ลดความถี่ลงเพื่อไม่ให้ล้น Serial)
//         static unsigned long lastPrint = 0;
//         if (millis() - lastPrint >= 100) {  // Print every 100ms
//             Serial.printf("Roll: %.1f  Pitch: %.1f  Yaw: %.1f\n", 
//                       imu.getRoll(),imu.getPitch(), imu.getMagYaw());
//             // Serial.printf("Roll: %.1f  Pitch: %.1f  Yaw: %.1f\n Alt: %.3f\n", 
//             //           state_est[0]* (180.0f/PI), state_est[1]* (180.0f/PI), state_est[2]* (180.0f/PI),Altitude);
//             // Serial.printf("Alt: %.3f\n",Altitude);
//             lastPrint = millis();
//         }
        
//         // PID Control & Servo (no I2C needed)
//         // ctrl.update();
//         rov.update();

//         // Maintain precise 100Hz timing
//         vTaskDelayUntil(&xLastWakeTime, xFrequency);
//     }
// }

// // ============================================
// // CORE 1: MICRO-ROS TASK (Communication)
// // Priority: 2 (High)
// // Frequency: As fast as possible
// // ============================================
// void taskMicroROS(void *parameter) {
//     Serial.println("📡 Core 1: micro-ROS task started");
    
//     while(1) {
//         if (wifi_connected) {
//             runMicroROS();
//             stopPublishing();
//             if (xSemaphoreTake(dataMutex, pdMS_TO_TICKS(2)) == pdTRUE) {
//                 agent_connected = isAgentConnected();
//                 xSemaphoreGive(dataMutex);
//             }
            
//             updateStatusLED(wifi_connected, agent_connected, false);
//         } else {
//             vTaskDelay(pdMS_TO_TICKS(100));
//         }
        
//         vTaskDelay(pdMS_TO_TICKS(1)); // Minimal delay for task switching
//     }
// }

// // ============================================
// // CORE 1: GPS TASK (Serial Communication)
// // Priority: 2 (High)
// // Frequency: 10ms
// // ============================================
// void taskGPS(void *parameter) {
//     Serial.println("🛰️ Core 1: GPS task started");
//     TickType_t xLastWakeTime = xTaskGetTickCount();
//     const TickType_t xFrequency = pdMS_TO_TICKS(10);
    
//     unsigned long lastPrint = 0;
    
//     while(1) {
//         GPSData gpsData = getGPSData();
        
//         // Print every 1 second
//         if (millis() - lastPrint >= 1000) {
//             if (gpsData.isValid) {
//                 Serial.println("✓ GPS has valid fix!");
//                 // REMOVED: Distance calculation from WiFi Pos
//             }
//             lastPrint = millis();
//         }
        
//         vTaskDelayUntil(&xLastWakeTime, xFrequency);
//     }
// }

// // ============================================
// // CORE 1: DISPLAY TASK (I2C Communication)
// // Priority: 1 (Normal)
// // Frequency: 500ms
// // ============================================
// void taskDisplay(void *parameter) {
//     Serial.println("📺 Core 1: Display task started");
//     TickType_t xLastWakeTime = xTaskGetTickCount();
//     const TickType_t xFrequency = pdMS_TO_TICKS(500);
    
//     unsigned long lastPageSwitch = 0;
//     const unsigned long PAGE_SWITCH_INTERVAL = 5000;
    
//     while(1) {
//         // Auto switch page
//         if (millis() - lastPageSwitch >= PAGE_SWITCH_INTERVAL) {
//             switchDisplayPage();
//             lastPageSwitch = millis();
//         }
        
//         // Update display with I2C mutex
//         if (xSemaphoreTake(i2cMutex, pdMS_TO_TICKS(20)) == pdTRUE) {
//             GPSData gpsData = getGPSData();
            
//             switch(currentPage) {
//                 case 0:
//                     displayGPSPage();
//                     break;
//                 case 1:
//                     displayWiFiPage(WIFI_SSID, wifi_connected, agent_connected);
//                     break;
//                 case 2:
//                     // MODIFIED: เดิมคือ displayPositionPage(wifiPos, gpsData);
//                     // เปลี่ยนเป็นแสดงหน้า GPS แทนเนื่องจากไม่มี wifiPos แล้ว
//                     displayGPSPage(); 
//                     break;
//             }
            
//             xSemaphoreGive(i2cMutex);
//         }
        
//         vTaskDelayUntil(&xLastWakeTime, xFrequency);
//     }
// }
// void enableDLPF() {
//     Wire.beginTransmission(0x68);
//     Wire.write(0x1A); 
//     Wire.write(0x05); 
//     Wire.endTransmission();
//     Serial.println("DLPF Enabled");
// }

// void setupDroneParams() {
//     p.m = 0.7f;         
//     p.g = 9.81f;

//     p.l = 0.048f;
//     p.r = 0.029f;
//     p.Ixx = 0.01f;
//     p.Iyy = 0.01f;
//     p.Izz = 0.02f;
    
//     // Aerodynamics
//     p.C_L_alpha = 0.108f; 
//     p.C_D_0 = 0.01f;
//     p.A_fin = 0.0028f;
//     p.A_duct = 0.0038f;
    
//     // Motor
//     p.K_f = 1.05e-6f;

//     memset(p.K_f_matrix, 0, sizeof(p.K_f_matrix));

//     float gain_gyro = 0.02f;

//     p.K_f_matrix[0][0] = 0.005; 
//     p.K_f_matrix[1][1] = 0.005; 
//     p.K_f_matrix[2][2] = 0.02f; 
//     p.K_f_matrix[3][3] = gain_gyro; 
//     p.K_f_matrix[4][4] = gain_gyro; 
//     p.K_f_matrix[5][5] = gain_gyro;

//     Tewadon.setParams(p);
// }
// // ============================================
// // SETUP (Runs on Core 1)
// // ============================================
// void setup() {
//     Serial.begin(115200);
//     delay(2000);
    
//     // Create mutexes FIRST
//     i2cMutex = xSemaphoreCreateMutex();
//     dataMutex = xSemaphoreCreateMutex();
    
//     if (i2cMutex == NULL || dataMutex == NULL) {
//         Serial.println("❌ Failed to create mutexes!");
//         ESP.restart();
//     }
    
//     // Initialize I2C
//     Serial.println("\n=== Initializing I2C Bus ===");
//     Wire.begin(I2C_SDA, I2C_SCL);
//     Wire.setClock(400000);
//     Wire.setTimeout(100);
//     Serial.println("✅ I2C Bus initialized (SDA=8, SCL=9)");
//     delay(100);

//     // Initialize IMU
//     Serial.println("\n=== Initializing IMU ===");
//     if (!imu.begin()) {
//         Serial.println("❌ IMU initialization failed!");
//         Serial.println("Continuing without IMU...");
//     } else {
//         Serial.println("✅ IMU initialized successfully");
        
//         // ⚙️ ตั้งค่า IMU Rotation (เปลี่ยนได้ตรงนี้)
//         // imu.setRotation(ROTATION_CUSTOM_3);
//         imu.zeroOrientation();
        
//         // // 🧪 ทดสอบ IMU Rotation (Comment out หลังทดสอบเสร็จ)
//         // Serial.println("\n⏳ Waiting 3 seconds before IMU test...");
//         // delay(3000);
//         // imu.printOrientation();  // แสดงคำแนะนำ
//         // delay(2000);
//         // imu.testRotation(30);    // ทดสอบ 30 ตัวอย่าง (3 วินาที)
//         // Serial.println("✓ IMU test complete! Continuing setup...\n");
//         // delay(2000);
//     }
//     setupDroneParams();
//     memset(state_est, 0, sizeof(state_est));
//     last_time = micros();
//     enableDLPF(); 
//     delay(100);
//     // ToFinit();
//     delay(100);
//     // Initialize Controller
//     Serial.println("\n=== Initializing Controller ===");
//     // ctrl.begin();
//     delay(100);
    
//     // Initialize OLED
//     Serial.println("\n=== Initializing OLED Display ===");
//     initDisplay(); 
//     initLED();
    
//     Serial.println("\n🚀 ESP32-S3 Dual Core Configuration");
//     Serial.println("Core 0: IMU (100Hz) + Control");
//     Serial.println("Core 1: ROS + GPS + Display");
//     Serial.println();

//     // Initialize GPS
//     Serial.println("Initializing GPS...");
//     initGPS(GPS_RX_PIN, GPS_TX_PIN, GPS_BAUD);
    
//     // Connect WiFi
//     showMessage("Connecting WiFi...");
//     wifi_connected = initWiFi(WIFI_SSID, WIFI_PASSWORD);
//     if (!wifi_connected) {
//         Serial.println("WiFi connection failed! Restarting...");
//         showMessage("WiFi FAILED!", "Restarting...");
//         delay(2000);
//         ESP.restart();
//     }
    
    
//     // Initialize micro-ROS
//     showMessage("WiFi Connected!", "Connecting ROS...");
//     agent_connected = initMicroROS(WIFI_SSID, WIFI_PASSWORD, ros_config);
//     if (!agent_connected) {
//         Serial.println("micro-ROS initialization failed! Restarting...");
//         showMessage("ROS FAILED!", "Restarting...");
//         delay(2000);
//         ESP.restart();
//     }
        
//     Serial.println("\n=== Creating Tasks ===");
    
//     // CORE 0: IMU & Control (Highest Priority)
//     xTaskCreatePinnedToCore(
//         taskIMUControl,           // Task function
//         "IMU_Control",            // Task name
//         4096,                     // Stack size
//         NULL,                     // Parameters
//         3,                        // Priority (Highest)
//         &taskIMUHandle,           // Task handle
//         CORE_IMU_CONTROL          // Core 0
//     );
//     Serial.println("✅ Core 0: IMU & Control task created (Priority: 3)");
    
//     // CORE 1: micro-ROS (High Priority)
//     xTaskCreatePinnedToCore(
//         taskMicroROS,
//         "MicroROS",
//         8192,                     // Larger stack for ROS
//         NULL,
//         2,                        // Priority: High
//         &taskROSHandle,
//         CORE_COMM_UI              // Core 1
//     );
//     Serial.println("✅ Core 1: micro-ROS task created (Priority: 2)");
    
//     // CORE 1: GPS (High Priority)
//     xTaskCreatePinnedToCore(
//         taskGPS,
//         "GPS",
//         4096,
//         NULL,
//         2,                        // Priority: High
//         &taskGPSHandle,
//         CORE_COMM_UI              // Core 1
//     );
//     Serial.println("✅ Core 1: GPS task created (Priority: 2)");
    
//     // CORE 1: Display (Normal Priority)
//     xTaskCreatePinnedToCore(
//         taskDisplay,
//         "Display",
//         4096,
//         NULL,
//         1,                        // Priority: Normal
//         &taskDisplayHandle,
//         CORE_COMM_UI              // Core 1
//     );
//     Serial.println("✅ Core 1: Display task created (Priority: 1)");
    
//     rov.begin();
//     Serial.println("\n🎉 Setup complete! All tasks running.");
//     showMessage("Setup Complete!", "Tasks Running");
//     delay(2000);
// }

// // ============================================
// // LOOP (Runs on Core 1, but mostly idle now)
// // ============================================
// void loop() {
//     // Monitor WiFi connection (low priority background task)
//     static unsigned long lastWiFiCheck = 0;
//     if (millis() - lastWiFiCheck >= 5000) {
//         bool current_wifi_status = checkWiFiConnection();
        
//         if (current_wifi_status != wifi_connected) {
//             wifi_connected = current_wifi_status;
            
//             if (!wifi_connected) {
//                 agent_connected = false;
//                 reconnectWiFi(WIFI_SSID, WIFI_PASSWORD);
//                 wifi_connected = true;
//             }
//         }
        
//         lastWiFiCheck = millis();
//     }
    
//     // REMOVED: Loop update for WiFi Position
    
//     delay(1000); // Loop can be slow since all work is in tasks
// }

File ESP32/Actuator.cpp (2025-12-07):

#include "Actuator.h"

ROVController::ROVController() {
    // Default pins
    PIN_1 = 1;   // Front
    PIN_2 = 15;  // Right
    PIN_3 = 2;   // Left
    PIN_4 = 16;  // Back
    PIN_5 = 39;  // Thruster
    
    // Default center positions
    CENTER_1 = 70;  // Front
    CENTER_2 = 71;  // Right
    CENTER_3 = 64;  // Left
    CENTER_4 = 73;  // Back
    
    // Initialize positions
    current1 = CENTER_1;
    current2 = CENTER_2;
    current3 = CENTER_3;
    current4 = CENTER_4;
    current5 = 0;
    
    target1 = CENTER_1;
    target2 = CENTER_2;
    target3 = CENTER_3;
    target4 = CENTER_4;
    target5 = 0;
}

void ROVController::setPins(int pin1, int pin2, int pin3, int pin4, int pin5) {
    PIN_1 = pin1;
    PIN_2 = pin2;
    PIN_3 = pin3;
    PIN_4 = pin4;
    PIN_5 = pin5;
}

void ROVController::setCenterPositions(int c1, int c2, int c3, int c4) {
    CENTER_1 = c1;
    CENTER_2 = c2;
    CENTER_3 = c3;
    CENTER_4 = c4;
    
    current1 = target1 = CENTER_1;
    current2 = target2 = CENTER_2;
    current3 = target3 = CENTER_3;
    current4 = target4 = CENTER_4;
}

void ROVController::begin() {
    Serial.begin(115200);
    delay(1000);
    
    Serial.println("=== ROV Controller Starting ===");
    
    // Setup Servos 1-4
    Serial.println("Setting up Servo 1 (Front)...");
    servo1.setPeriodHertz(50);
    servo1.attach(PIN_1, 500, 2500);
    servo1.write(CENTER_1);
    delay(100);
    
    Serial.println("Setting up Servo 2 (Right)...");
    servo2.setPeriodHertz(50);
    servo2.attach(PIN_2, 500, 2500);
    servo2.write(CENTER_2);
    delay(100);
    
    Serial.println("Setting up Servo 3 (Left)...");
    servo3.setPeriodHertz(50);
    servo3.attach(PIN_3, 500, 2500);
    servo3.write(CENTER_3);
    delay(100);
    
    Serial.println("Setting up Servo 4 (Back)...");
    servo4.setPeriodHertz(50);
    servo4.attach(PIN_4, 500, 2500);
    servo4.write(CENTER_4);
    delay(100);
    
    Serial.println("Servos 1-4 ready!");
    
    // Setup Thruster
    Serial.println("⚠️  Setting up Thruster ESC...");
    servo5.setPeriodHertz(50);
    servo5.attach(PIN_5, 1000, 2000);
    delay(100);
    
    Serial.println("Arming ESC...");
    servo5.writeMicroseconds(1000);
    delay(3000);
    Serial.println("✅ Thruster Ready!");
    
    Serial.println("\n=== ROV Controller Ready ===");
    Serial.println("Center positions:");
    Serial.println("  1-Front:    " + String(CENTER_1) + "° (±10)");
    Serial.println("  2-Right:    " + String(CENTER_2) + "° (±10)");
    Serial.println("  3-Left:     " + String(CENTER_3) + "° (±10)");
    Serial.println("  4-Back:     " + String(CENTER_4) + "° (±10)");
    Serial.println("  5-Thruster: 0 (0-100)");
    Serial.println("\nCommands:");
    Serial.println("  center           → servos 1-4 to center");
    Serial.println("  1 <-10~10>       → servo 1 offset");
    Serial.println("  2 <-10~10>       → servo 2 offset");
    Serial.println("  3 <-10~10>       → servo 3 offset");
    Serial.println("  4 <-10~10>       → servo 4 offset");
    Serial.println("  5 <0~100>        → thruster power");
    Serial.println("  all <-10~10>     → all servos 1-4 same offset");
    Serial.println("  set <1> <2> <3> <4> → set all offsets");
    Serial.println("  stop             → thruster to 0");
    Serial.println("  status           → show current positions");
    Serial.println();
}

void ROVController::update() {
    processSerialCommand();
    updateServos();
    delayMicroseconds(800);
}

void ROVController::processSerialCommand() {
    if (!Serial.available()) return;
    
    String cmd = Serial.readStringUntil('\n');
    cmd.trim();
    
    if (cmd.length() == 0) return;
    
    Serial.print("[DEBUG] Received: '");
    Serial.print(cmd);
    Serial.println("'");
    
    String cmdLower = cmd;
    cmdLower.toLowerCase();
    
    if (cmdLower == "center") {
        moveToCenter();
        Serial.println("→ Servos 1-4 to center");
        
    } else if (cmdLower == "stop") {
        stop();
        
    } else if (cmdLower == "status") {
        showStatus();
        
    } else if (cmd.startsWith("1 ") || cmd.startsWith("1\t")) {
        int offset = cmd.substring(2).toInt();
        setServo(1, offset);
        
    } else if (cmd.startsWith("2 ") || cmd.startsWith("2\t")) {
        int offset = cmd.substring(2).toInt();
        setServo(2, offset);
        
    } else if (cmd.startsWith("3 ") || cmd.startsWith("3\t")) {
        int offset = cmd.substring(2).toInt();
        setServo(3, offset);
        
    } else if (cmd.startsWith("4 ") || cmd.startsWith("4\t")) {
        int offset = cmd.substring(2).toInt();
        setServo(4, offset);
        
    } else if (cmd.startsWith("5 ") || cmd.startsWith("5\t")) {
        int power = cmd.substring(2).toInt();
        setThruster(power);
        
    } else if (cmdLower.startsWith("all ")) {
        int offset = cmd.substring(4).toInt();
        setAllServos(offset);
        
    } else if (cmdLower.startsWith("set ")) {
        parseSetCommand(cmd);
        
    } else {
        Serial.println("❌ Unknown command: '" + cmd + "'");
    }
    
    while(Serial.available()) Serial.read();
}

void ROVController::moveToCenter() {
    target1 = CENTER_1;
    target2 = CENTER_2;
    target3 = CENTER_3;
    target4 = CENTER_4;
}

void ROVController::setServo(int servoNum, int offset) {
    offset = constrain(offset, -RANGE, RANGE);
    
    switch(servoNum) {
        case 1:
            target1 = CENTER_1 + offset;
            Serial.print("→ Servo 1 (Front): ");
            Serial.print(CENTER_1);
            Serial.print(offset >= 0 ? "+" : "");
            Serial.print(offset);
            Serial.print(" = ");
            Serial.print(target1);
            Serial.println("°");
            break;
            
        case 2:
            target2 = CENTER_2 + offset;
            Serial.print("→ Servo 2 (Right): ");
            Serial.print(CENTER_2);
            Serial.print(offset >= 0 ? "+" : "");
            Serial.print(offset);
            Serial.print(" = ");
            Serial.print(target2);
            Serial.println("°");
            break;
            
        case 3:
            target3 = CENTER_3 + offset;
            Serial.print("→ Servo 3 (Left): ");
            Serial.print(CENTER_3);
            Serial.print(offset >= 0 ? "+" : "");
            Serial.print(offset);
            Serial.print(" = ");
            Serial.print(target3);
            Serial.println("°");
            break;
            
        case 4:
            target4 = CENTER_4 + offset;
            Serial.print("→ Servo 4 (Back): ");
            Serial.print(CENTER_4);
            Serial.print(offset >= 0 ? "+" : "");
            Serial.print(offset);
            Serial.print(" = ");
            Serial.print(target4);
            Serial.println("°");
            break;
    }
}
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

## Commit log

2025-12-06 Add files via upload
    sim add
    [body.stl, drone.urdf.xacro, fin_1.stl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]
2025-12-06 Readme_rviz2
    Updated ROS2 nodes and topics in README.md to reflect changes in data flow and control commands.
2025-12-07 Add GIF demo for Thrust Vane Mechanism
2025-12-07 Revise control method to LQR and remove gallery
    Updated project scope to use LQR for control instead of PID. Removed gallery section for images.
